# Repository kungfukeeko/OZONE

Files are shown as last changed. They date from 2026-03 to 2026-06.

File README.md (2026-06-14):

------  MJERENJE STUPCA OZONA  ------

Ovdje nam se nalaze svi bitni file-ovi za proizvesti i programirati instrument ☀️

Prioritet je:

1. Ugladiti i kalibrirati suncokret 🌻
2. Programirati ESP32 feature u ozone_v2.ino: izračun pozicije sunca -DONE-, slanje mjerenja preko weba -DONE- i prikaz na ekranu -DONE-, sleep-wakeup kontrola -TODO-💫💽💤
3. Spojiti sunflower.ino i ozone_v2.ino 👯
4. Dizajnirati poklopac za platformu ⛺
5. Redizajnirati platformu za metalni servo na vertikalnoj osi 🔭

Kako bi primili podatke preko WiFi-a na kraju mjerenja
- Create secrets.h , copy secrets.example.h and add your SECRET_WIFI_SSID, SECRET_WIFI_PASS, SECRET_PC_HOST
- Windows: install nmap and run command before measurement end: ncat -l 5000 > data.csv
- macOS : no need to install nmap, just run: nc -l 5000 > data.csv

File će biti spremljen pod data.csv, preimenuj ga prije idućeg mjerenja.
Ovo ću update-at po potrebi.

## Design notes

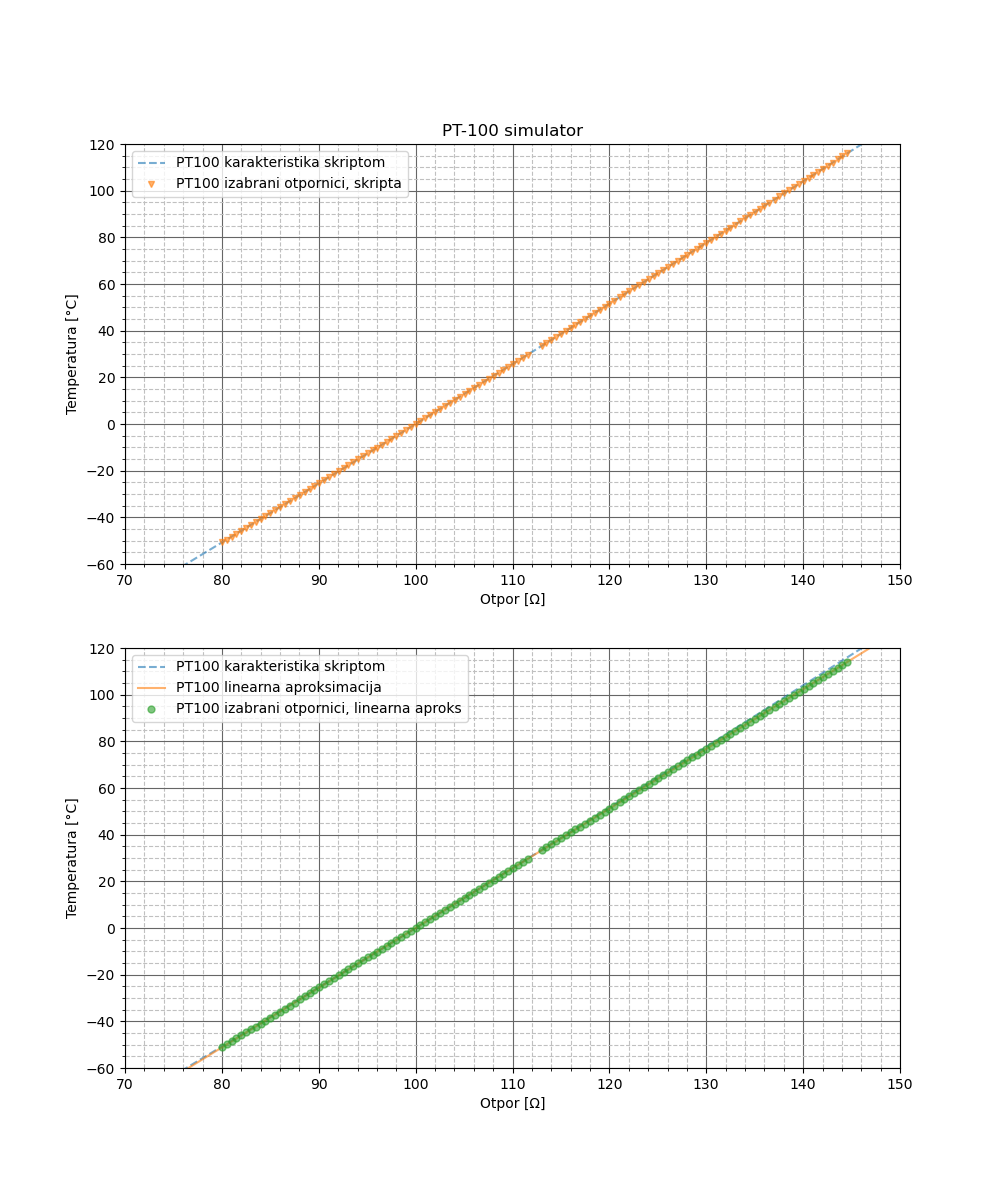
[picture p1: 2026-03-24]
Python - modeliranje i mjerenja/pt-100.png

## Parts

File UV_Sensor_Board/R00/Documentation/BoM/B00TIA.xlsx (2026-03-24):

Quantity | Designator | Manufacturer_Part_Number | JLC_Part_Number | Manufacturer_Name | Description | Footprint | MountingType | POPISČINA
1 | A1 | LP5907MFX-3.3/NOPB |  | Texas Instruments | LDO Voltage Regulators 250mA Ultra-Lo Noise LDO Reg | SOT-23-5 | SMD | Mouser
5 | C1, C12:1, C12:2, C14:1, C14:2 | C0805H103K5GACTU | CL21B103KBANNNC | Kemet | Multilayer Ceramic Capacitors MLCC - SMD/SMT 50V 0.01uF C0G 0805 10% | 0805 | SMD | Borealis
8 | C2, C3, C7, C8, C16:1, C16:2, C18:1, C18:2 | C0805C105K5RACTU | CL21B105KAFNFNE |  | Multilayer Ceramic Capacitors MLCC - SMD/SMT 50V 1uF X7R 0805 10% | 0805 | SMD | G4-4
1 | C4 | T495D106M035ATE250 | 293D106X9050E2TE3 | Kemet | Capacitor, Tantalum, 10uF, 35V, 20%, Low ESR, 250mΩ, Kemet | 2917 | SMD | G5-4 ili Borealis
9 | C5, C6, C10, C13:1, C13:2, C15:1, C15:2, C17:1, C17:2 | C0805C104K5RACTU | CL21B104KBCNNNC | Kemet | Multilayer Ceramic Capacitors MLCC - SMD/SMT 50V 0.1uF X7R 0805 10% | 0805 | SMD | G3-2 i G3-3
1 | C9 | C0603X224J5RACTU | 0603B224K250NT | Kemet | Multilayer Ceramic Capacitors MLCC - SMD/SMT 50V 0.22uF X7R 125C 0603 | 0603 | SMD | G3-6
2 | C11:1, C11:2 | C0805C101J5GAC3123 | CL21C101JBANNNC | Kemet | Multilayer Ceramic Capacitors MLCC - SMD/SMT 50V 100pF C0G 0805 5% | 0805 | SMD | G1-5
2 | D1:1, D1:2 | SG01S-18 |  | Sglux | SG01 series photodiode, TO18 housing | TO18 | THT
1 | FL1 | BLM21SP601BH1D | BLM21PG300SN1D | Murata Electronics | Ferrite Beads 600 OHM 2.3A FERRITE-BEAD | 0805 | SMD | H1-6 ali je 0603
1 | IC1 | ADS131M03IPWR |  | Texas Instruments | Analog to Digital Converters - ADC Three-channel 24-bi t 64-kSPS | TSSOP-20 | SMD | J-5-6
2 | IC2:1, IC2:2 | OPA387DBVT |  | Texas Instruments | Precision Amplifiers Ultra-high precision (2 uV) zero-drift | SOT-23-5 | SMD | Mouser
2 | IC3:1, IC3:2 | LMP7721MA |  | Texas Instruments | Precision Amplifiers 3 FEMTOAMPERE INPUT BIAS CURR PREC AMP | SOIC-8 | SMD | Mouser
1 | J1 | 61301611121 | / | Wurth Elektronik | Headers & Wire Housings WR-PHD 2.54mm Hdr 16 P Single Str Gold |  | THT
1 | J2 | 61301211121 | / | Wurth Elektronik | Headers & Wire Housings WR-PHD 2.54mm Hdr 12 P Single Str Gold |  | THT
7 | J3, J4, J5, J6, J7, J8, J9 | 61300211121 | / | Wurth Elektronik | Headers & Wire Housings WR-PHD 2.54mm 2Pin T HT Header |  | THT
7 | R1, R8:1, R8:2, R9:1, R9:2, R10:1, R10:2 | CRCW08051K00JNEC | 0805W8F1001T5E | Vishay | Thick Film Resistors D12/CRCW0805 200 1K0 5% ET6 e3 | 0805 | SMD | E4-6
3 | R3, R4, R5 | CRCW080510K0FKEA | 0805W8F1002T5E | Vishay | Thick Film Resistors 1/8watt 10Kohms 1% 100ppm | 0805 | SMD | F1-2
2 | R6:1, R6:2 | CRHV1206AF20M0FKFT | 1206W4F2005T5E | Vishay | Thick Film Resistors 20Mohms 1% 100ppm 0.3watt 3-side term | 1206 | SMD | Mouser
2 | R7:1, R7:2 | CRCW08054K70FKEA | 0805W8F4701T5E | Vishay | Resistor, Thick Film, 4K7, 1%, 0.125W, TK100, Vishay | 0805 | SMD | E5-6
2 | R11:1, R11:2 |  | 0805W8F0000T5E | Vishay | 0R | 0805 | SMD | E1-1
2 | X1:1, X1:2 | 73251-3140 | / | Molex | Connector, Receptacle, SMA, RF, 50Ohm, Molex |  | THT
1 | Y1 | ECS-2520MVLC-080-BN-TR | OT25208MJBA4SL | ECS | Standard Clock Oscillators MultiVolt ECS-2520MVLC,Active,XO (Standard),8MHz,Enable/Disable,CMOS,1.8V, 2.5V, 3.3V,+/-50ppm,-40C - 85C,Surface Mount,4-SMD, No Lead,0.098" L x 0.079" W (2.50mm x 2.00mm),0.035" (0.90mm) | SMD2520-4P | SMD | Mouser

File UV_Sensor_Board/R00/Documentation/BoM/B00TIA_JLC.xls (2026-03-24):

Comment | Designator | Footprint | JLCPCB Part #
ECS | Y1 | SMD2520-4P | C717682
Vishay | R6:1,R6:2 | 1206 | C71198
TexasInstruments | IC3:1,IC3:2 | SOIC-8 | C124427
Vishay | R7:1,R7:2 | 0805 | C17673
MultilayerCeramicCapacitorsMLCC-SMD/SMT50V0.22uFX7R125C0603 | C9 | C0603X224J5RACTU | C1606
Kemet | C1,C12:1,C12:2,C14:1,C14:2 | 0805 | C1710
Kemet | C11:1,C11:2 | 0805 | C1790
MurataElectronics | FL1 | 805 | C16903
 | C2,C3,C7,C8,C16:1,C16:2,C18:1,C18:2 | 0805 | C1712
TexasInstruments | IC1 | TSSOP-20 | C5215163
TexasInstruments | IC2:1,IC2:2 | SOT-23-5 | C4370041
ThickFilmResistorsD12/CRCW08052001K05%ET6e3 | R1,R8:1,R8:2,R9:1,R9:2,R10:1,R10:2 | 0805W8F1001T5E | C17513
Kemet | C5,C6,C10,C13:1,C13:2,C15:1,C15:2,C17:1,C17:2 | 0805 | C1711
Vishay | R3,R4,R5 | 0805 | C17414
0R | R11:1,R11:2 | 0805W8F0000T5E | C17477
TexasInstruments | A1 | SOT-23-5 | C80670
Kemet | C4 | 2917 | C1952737

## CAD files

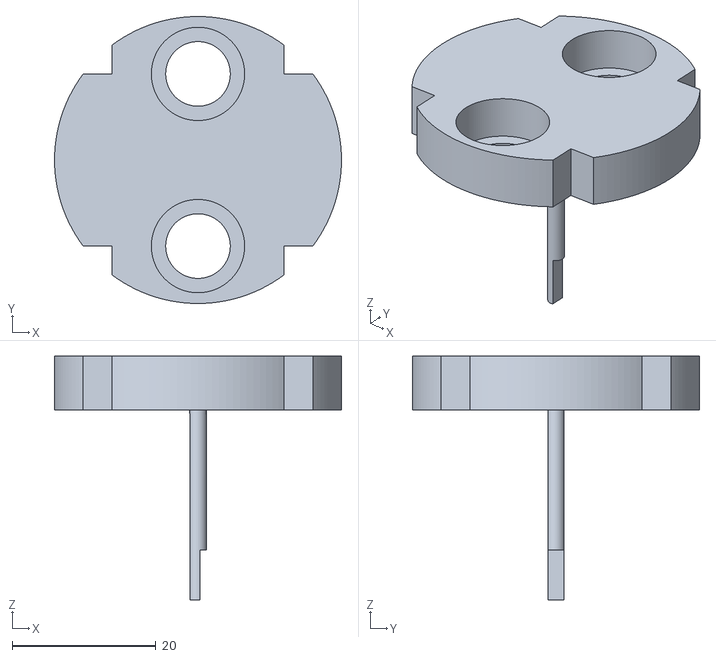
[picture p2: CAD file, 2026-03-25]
Filter_Holder/casev3-FILTER2.stl
40.0 x 40.0 x 34.0

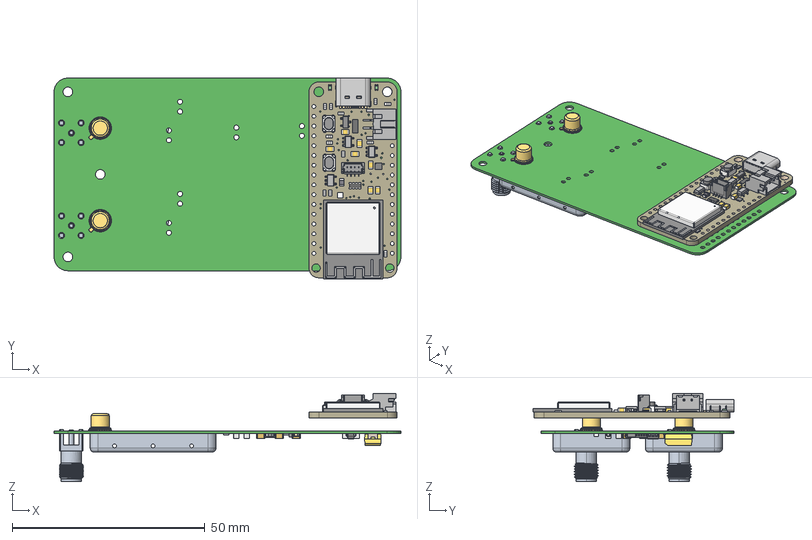
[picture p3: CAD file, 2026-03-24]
UV_Sensor_Board/R00/Documentation/STEP_model/PB00TIA.step
90.0 x 52.2 x 22.9 mm
Leader x 5
Mid_Body x 14
Mark x 14
Case_Bottom_Tant3
Case_Top_Tant3
Case_Cathode_Tant3
Case_Anode_Tant3
term1 x 2
term2 x 2
BODY-SOT x 2
LEAD-SOT x 10
LEAD-DUMMY x 2
C0603
Pins
BODY-SO x 2
LEAD-D0008A x 16
BODY-TSSOP
LEAD-TSSOP x 20
PIN1
MS326-10F x 2
Board
0805-NO x 7
SOT23-5 x 3
SOD-123
JSTPH2_BATT
CHIPLED_0603_NOOUTLINE x 2
0603-NO x 12
BTN_KMR2_4.6X2.8 x 2
SOT23-R
USB_C_CUSB31-CFM2AX-01-X
QFN60_ESP32-S2-MINI-1_EXP
WLCSP9
JST_SH4_RA
SK6805_1515
_0805MP
RESPACK_4X0603

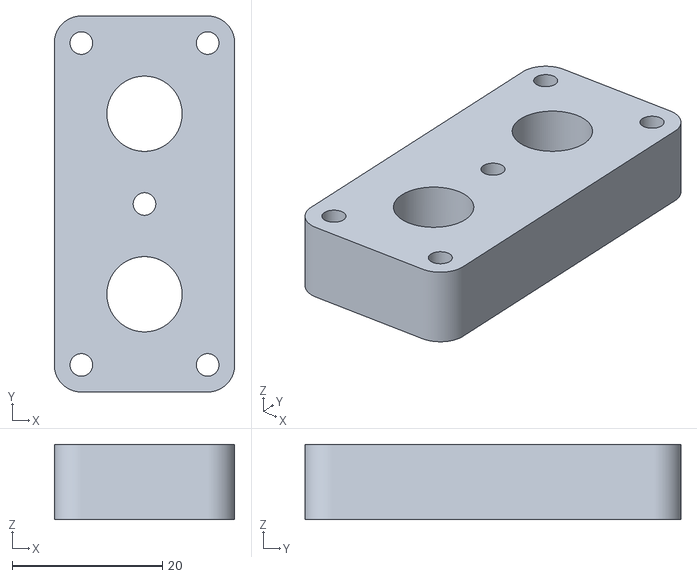
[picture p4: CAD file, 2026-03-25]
Filter_Holder/casev3-BASE.stl
24.0 x 50.0 x 10.0

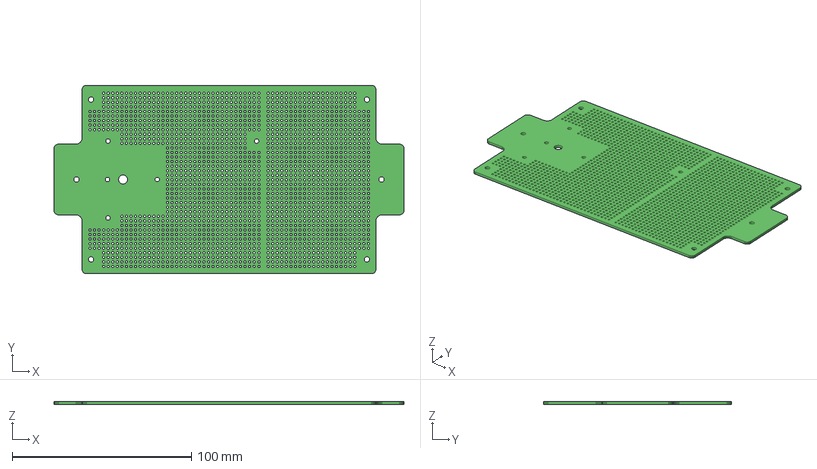
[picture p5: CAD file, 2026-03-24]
UV_Sensor_Board/R00/Documentation/STEP_model/protorupe.step
195.0 x 105.0 x 1.59 mm

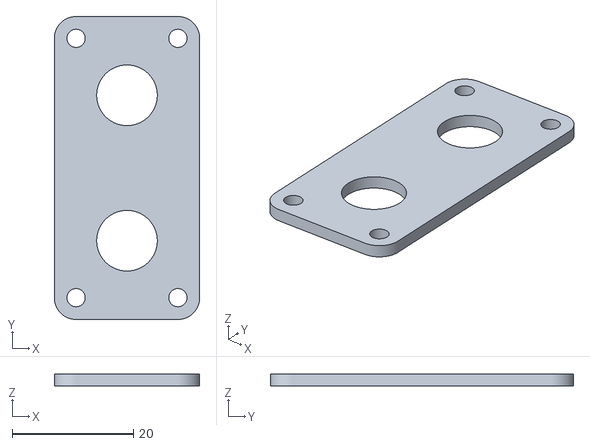
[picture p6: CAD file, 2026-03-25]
Filter_Holder/casev3-COVER.stl
24.0 x 50.0 x 2.00

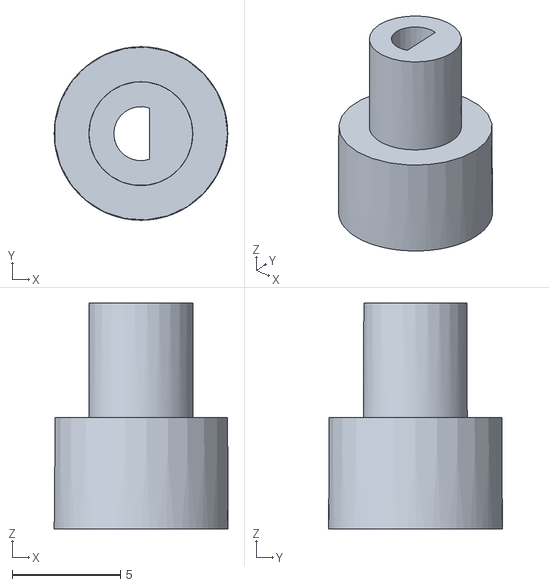
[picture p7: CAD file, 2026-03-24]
Filter_Holder/casev3-COUPLER_SCALED.stl
8.03 x 8.03 x 10.4

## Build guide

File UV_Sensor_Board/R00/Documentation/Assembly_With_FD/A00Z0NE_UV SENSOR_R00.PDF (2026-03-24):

A

B

C

D

E

1 | 1
2 | 2
3 | 3
4 | 4

# Assembly Instructions

- All used additional materials and procedures in the process must comply with REACH and RoHS EU directives.
- All processes must be carried out in accordance with J-STD-001 and IPC-7711/IPC-7721 Class 2, IEC 61340-5.
- The final result of all processes must meet IPC-A-610 Class 2.
- The standards, norms, directives, procedures that are mentioned must be used in the latest valid edition.

General instructions for applying additional surface protection - a layer of coating, valid for both sides of the PCB:

# Surface protection:

- Sheets 3 and 4 show the assembly of components.
- Sheets 5 and 6 show the surface protection.

# Remark:

Sheet: | Sheets:
4 | 4 | PromjeneAss | 4 | Ovaj dokument ostaje u isključivom vlasništvu KONČAR - INSTITUT ZA ELEKTROTEHNIKU. Pretisak i upotreba izvan namjene nisu dozvoljeni. | | Date: 29.5.2025. | Title: UV SENSOR | Number: A00Z0NE
| | | | | | Author: K.Stepančić
| | | | | | Checked By: M.Babić
| | PromjeneAss | | | | Approved By: D.Babić
Ed. | Version | Date | Name | | fiet 40422a/2

## File: A00Z0NE_UV SENSOR_R00.Pdf

This document remains the exclusive property of the KONČAR - ELECTRICAL ENGINEERING INSTITUTE. Reproduction or any use not in conformity with
the intended application is not permissible.

Revision:

Instructions for carrying out the process of assembly, testing, finishing, repair and final control:

- The module must necessarily undergo a washing process, i.e. removal of flux residues, grease, etc. before coating.
- The module must necessarily undergo a drying process before coating, at approximately the following temperature/duration: 60°C/6h or 40°C/12h.
- It is necessary to coat masked and unmasked traces, exposed parts of the PCB, component solder joints or exposed contacts.
- If the component is not mounted, it is necessary to coat the empty solder joints of the component.
- Coating of the module is possible manually and mechanically.
- The final result must meet IPC-A-610 Class 2, the thickness of the coating must be within the limits of 0.03-0.13mm.

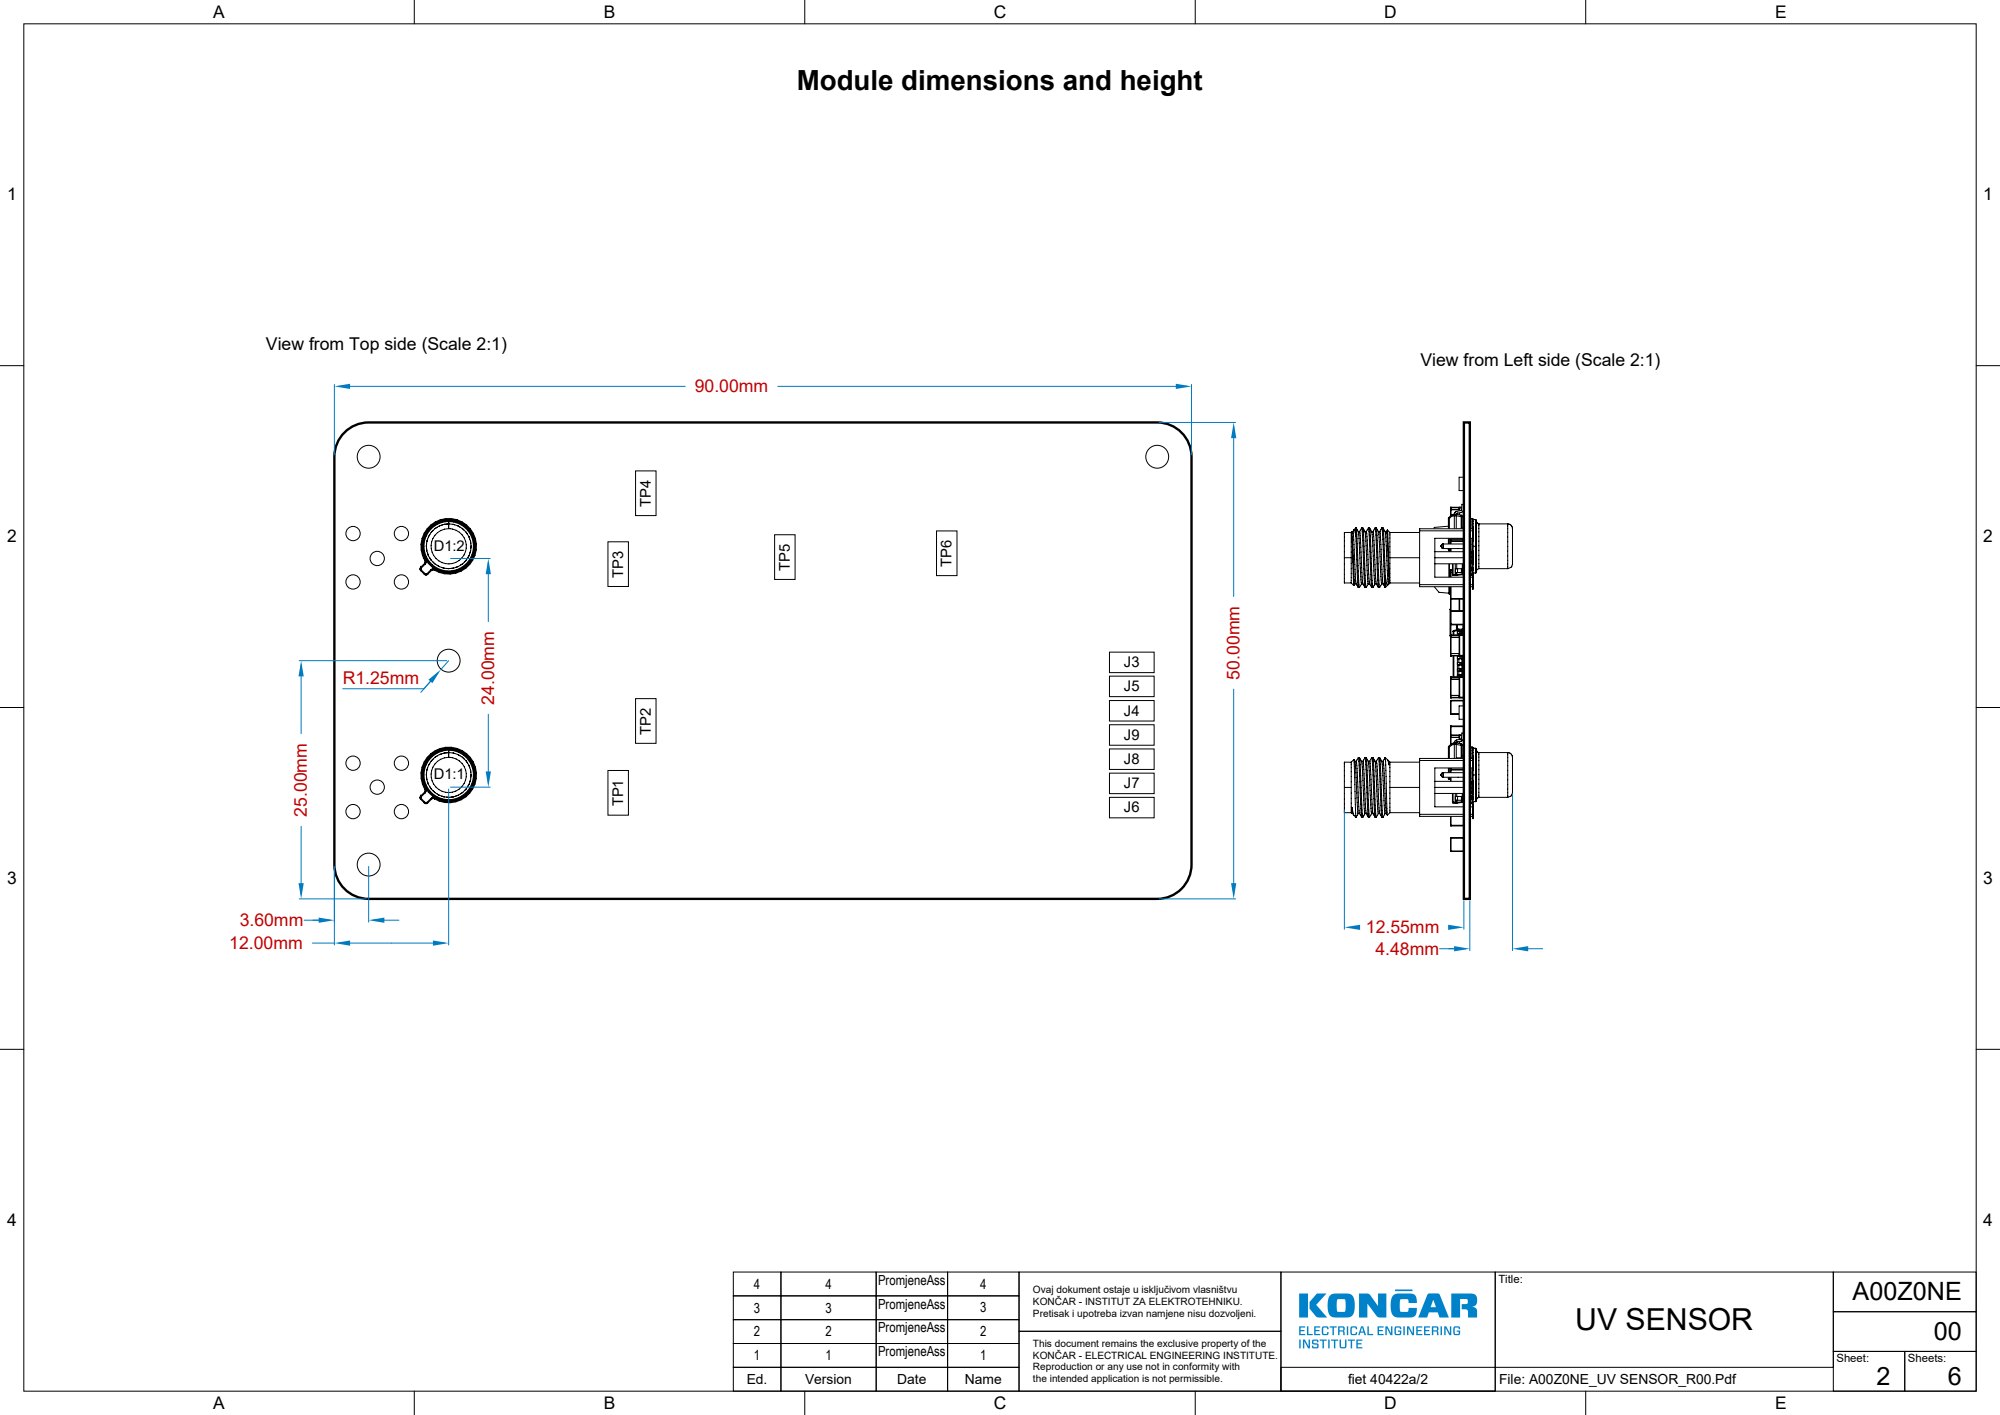
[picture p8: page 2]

Module dimensions and height

View from Top side (Scale 2:1)

View from Left side (Scale 2:1)

Ovaj dokument ostaje u isključivom vlasništvu

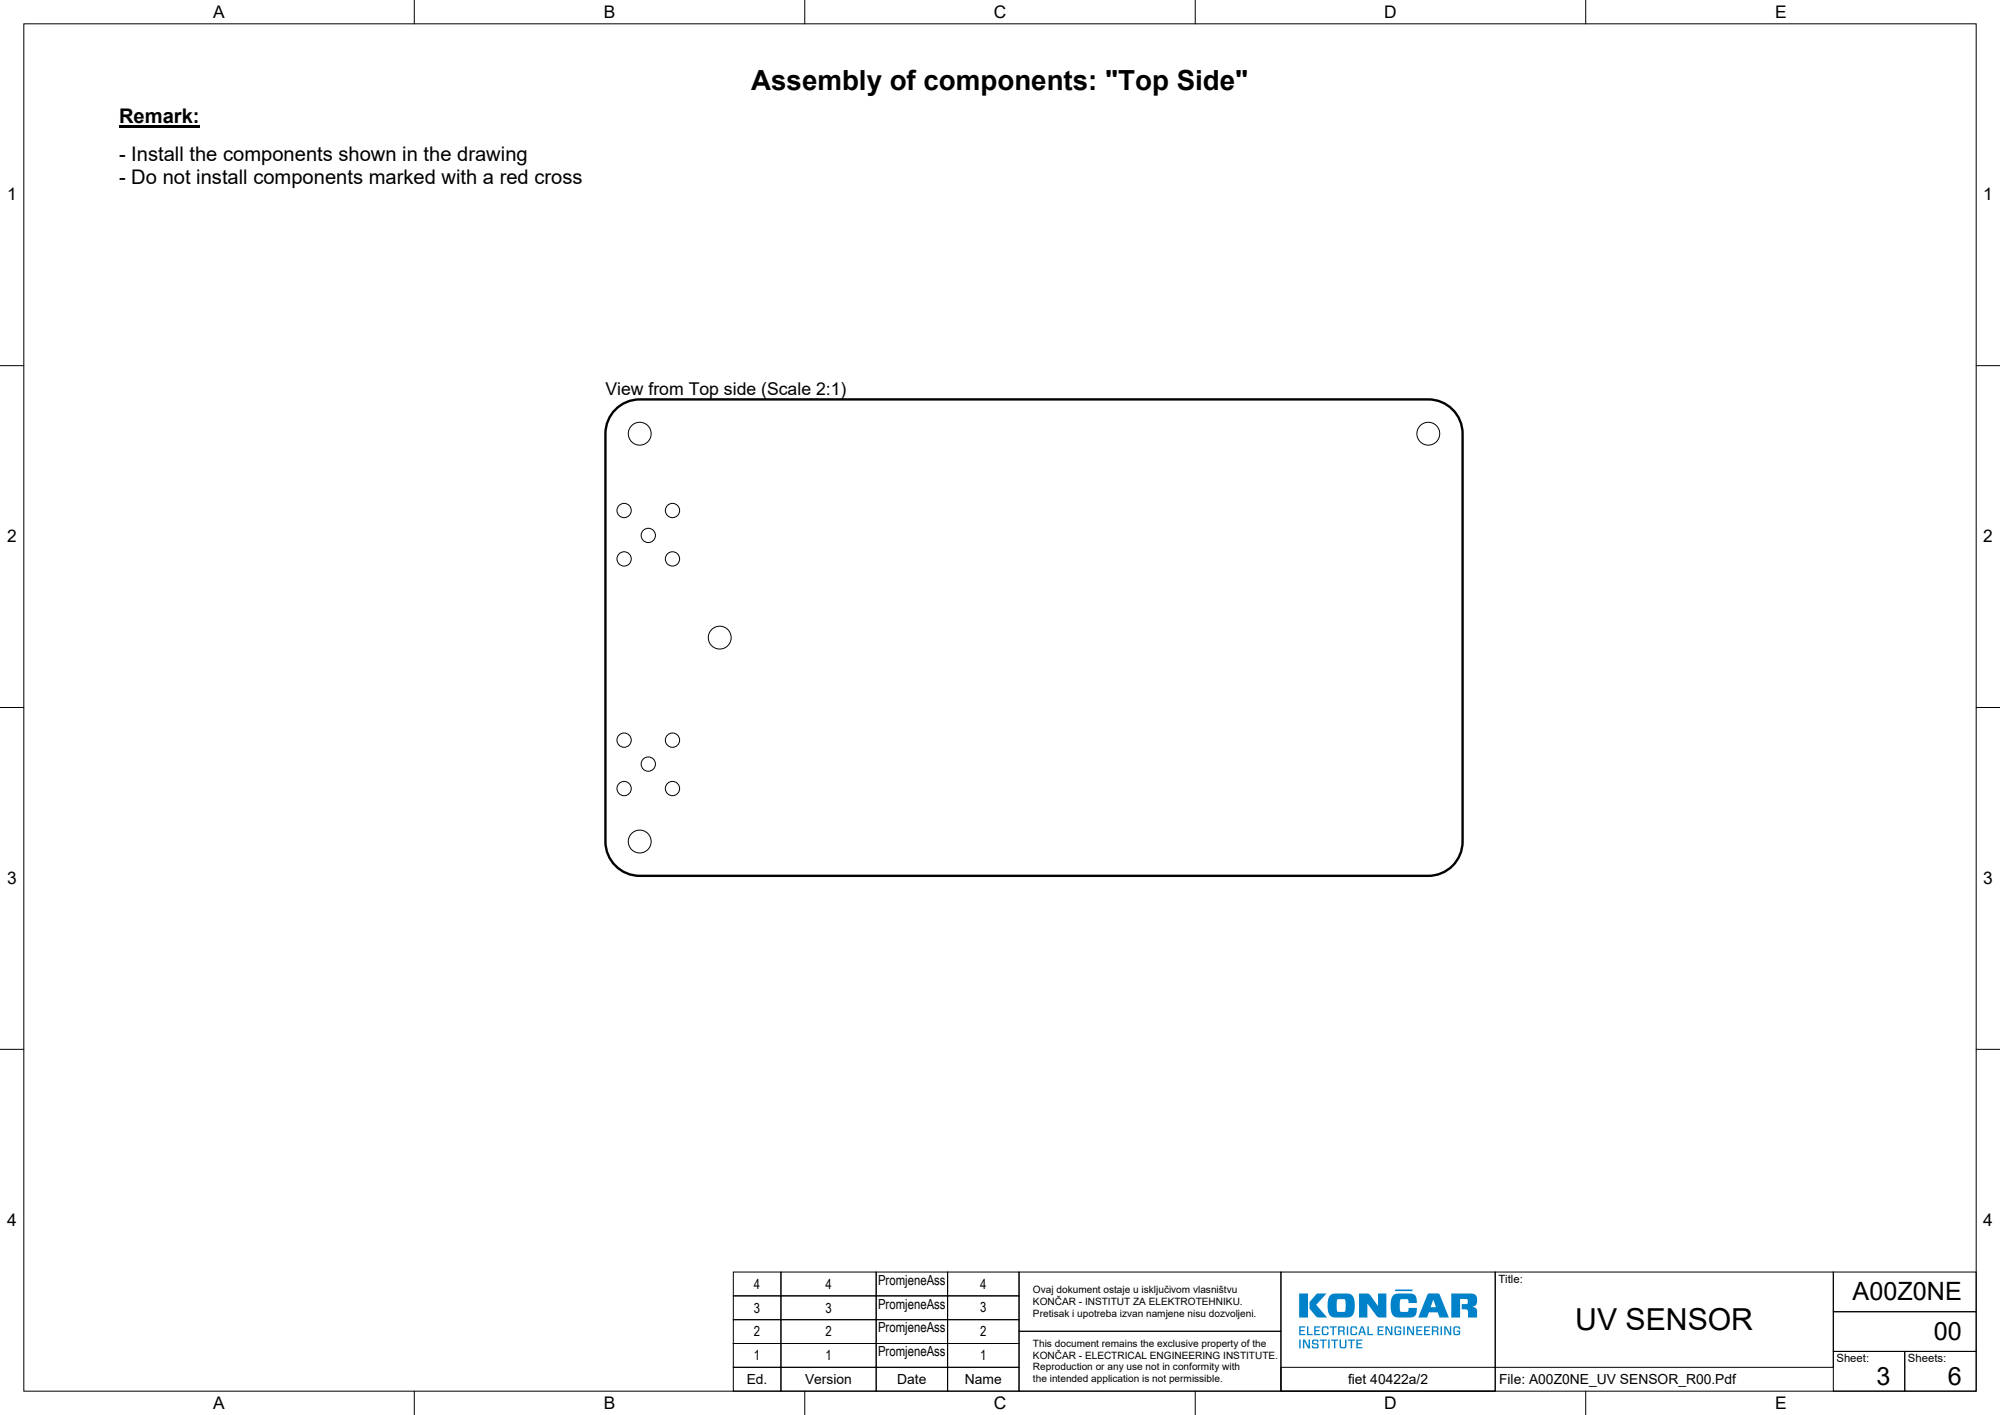
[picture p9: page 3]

Assembly of components: "Top Side"

Remark:
- Install the components shown in the drawing
- Do not install components marked with a red cross

View from Top side (Scale 2:1)

Ovaj dokument ostaje u isključivom vlasništvu

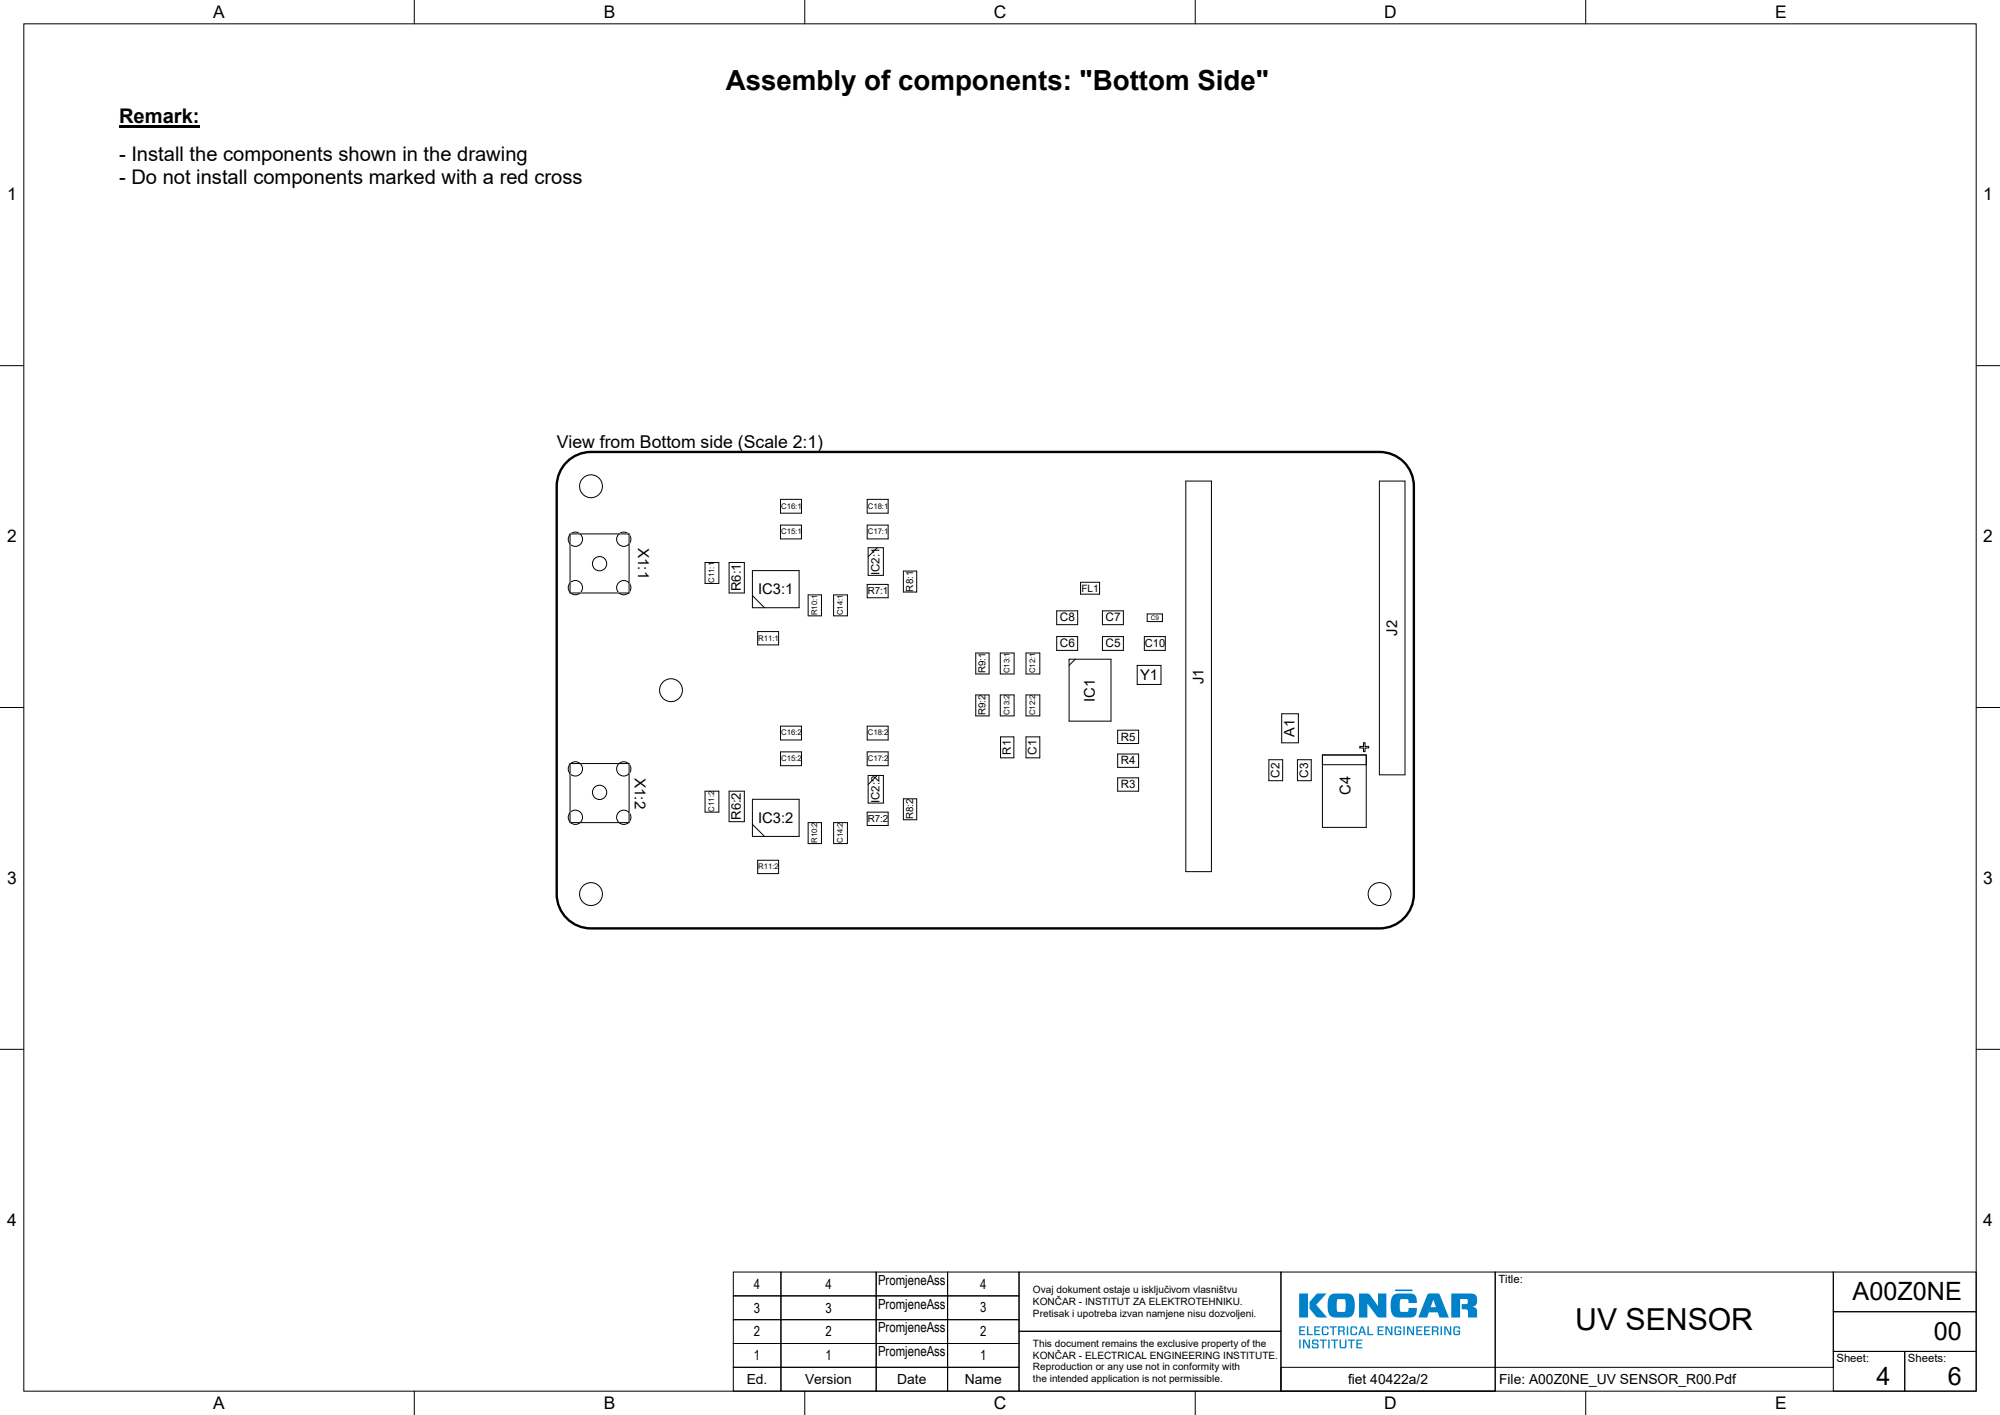
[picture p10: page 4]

Assembly of components: "Bottom Side"

- Install the components shown in the drawing
- Do not install components marked with a red cross

View from Bottom side (Scale 2:1)

Ovaj dokument ostaje u isključivom vlasništvu

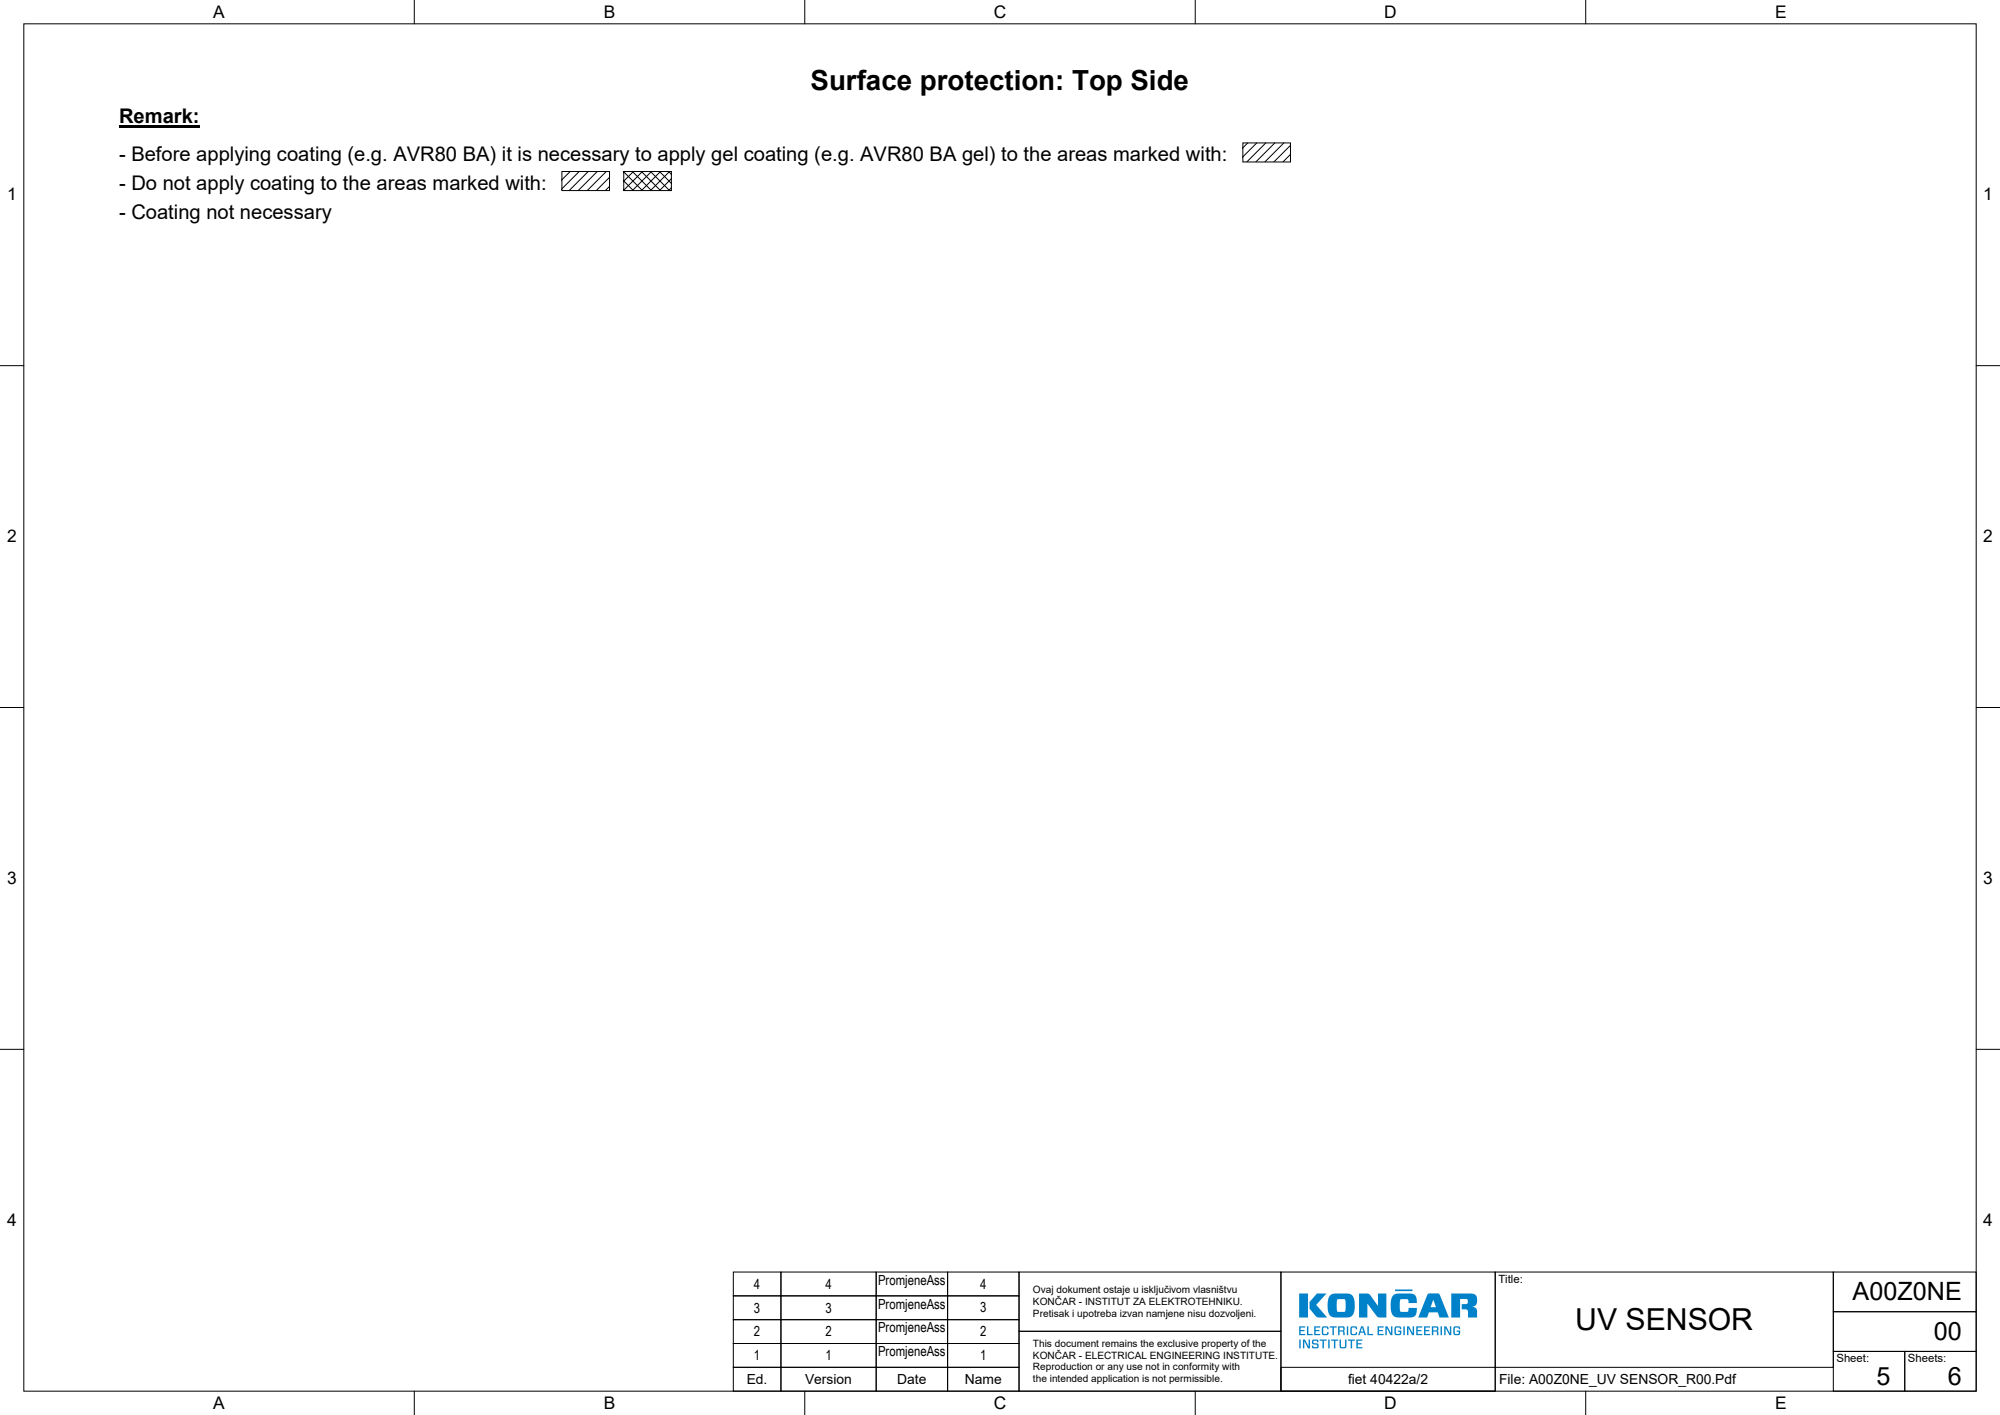
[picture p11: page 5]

Surface protection: Top Side

- Before applying coating (e.g. AVR80 BA) it is necessary to apply gel coating (e.g. AVR80 BA gel) to the areas marked with:
- Do not apply coating to the areas marked with:
- Coating not necessary

Ovaj dokument ostaje u isključivom vlasništvu

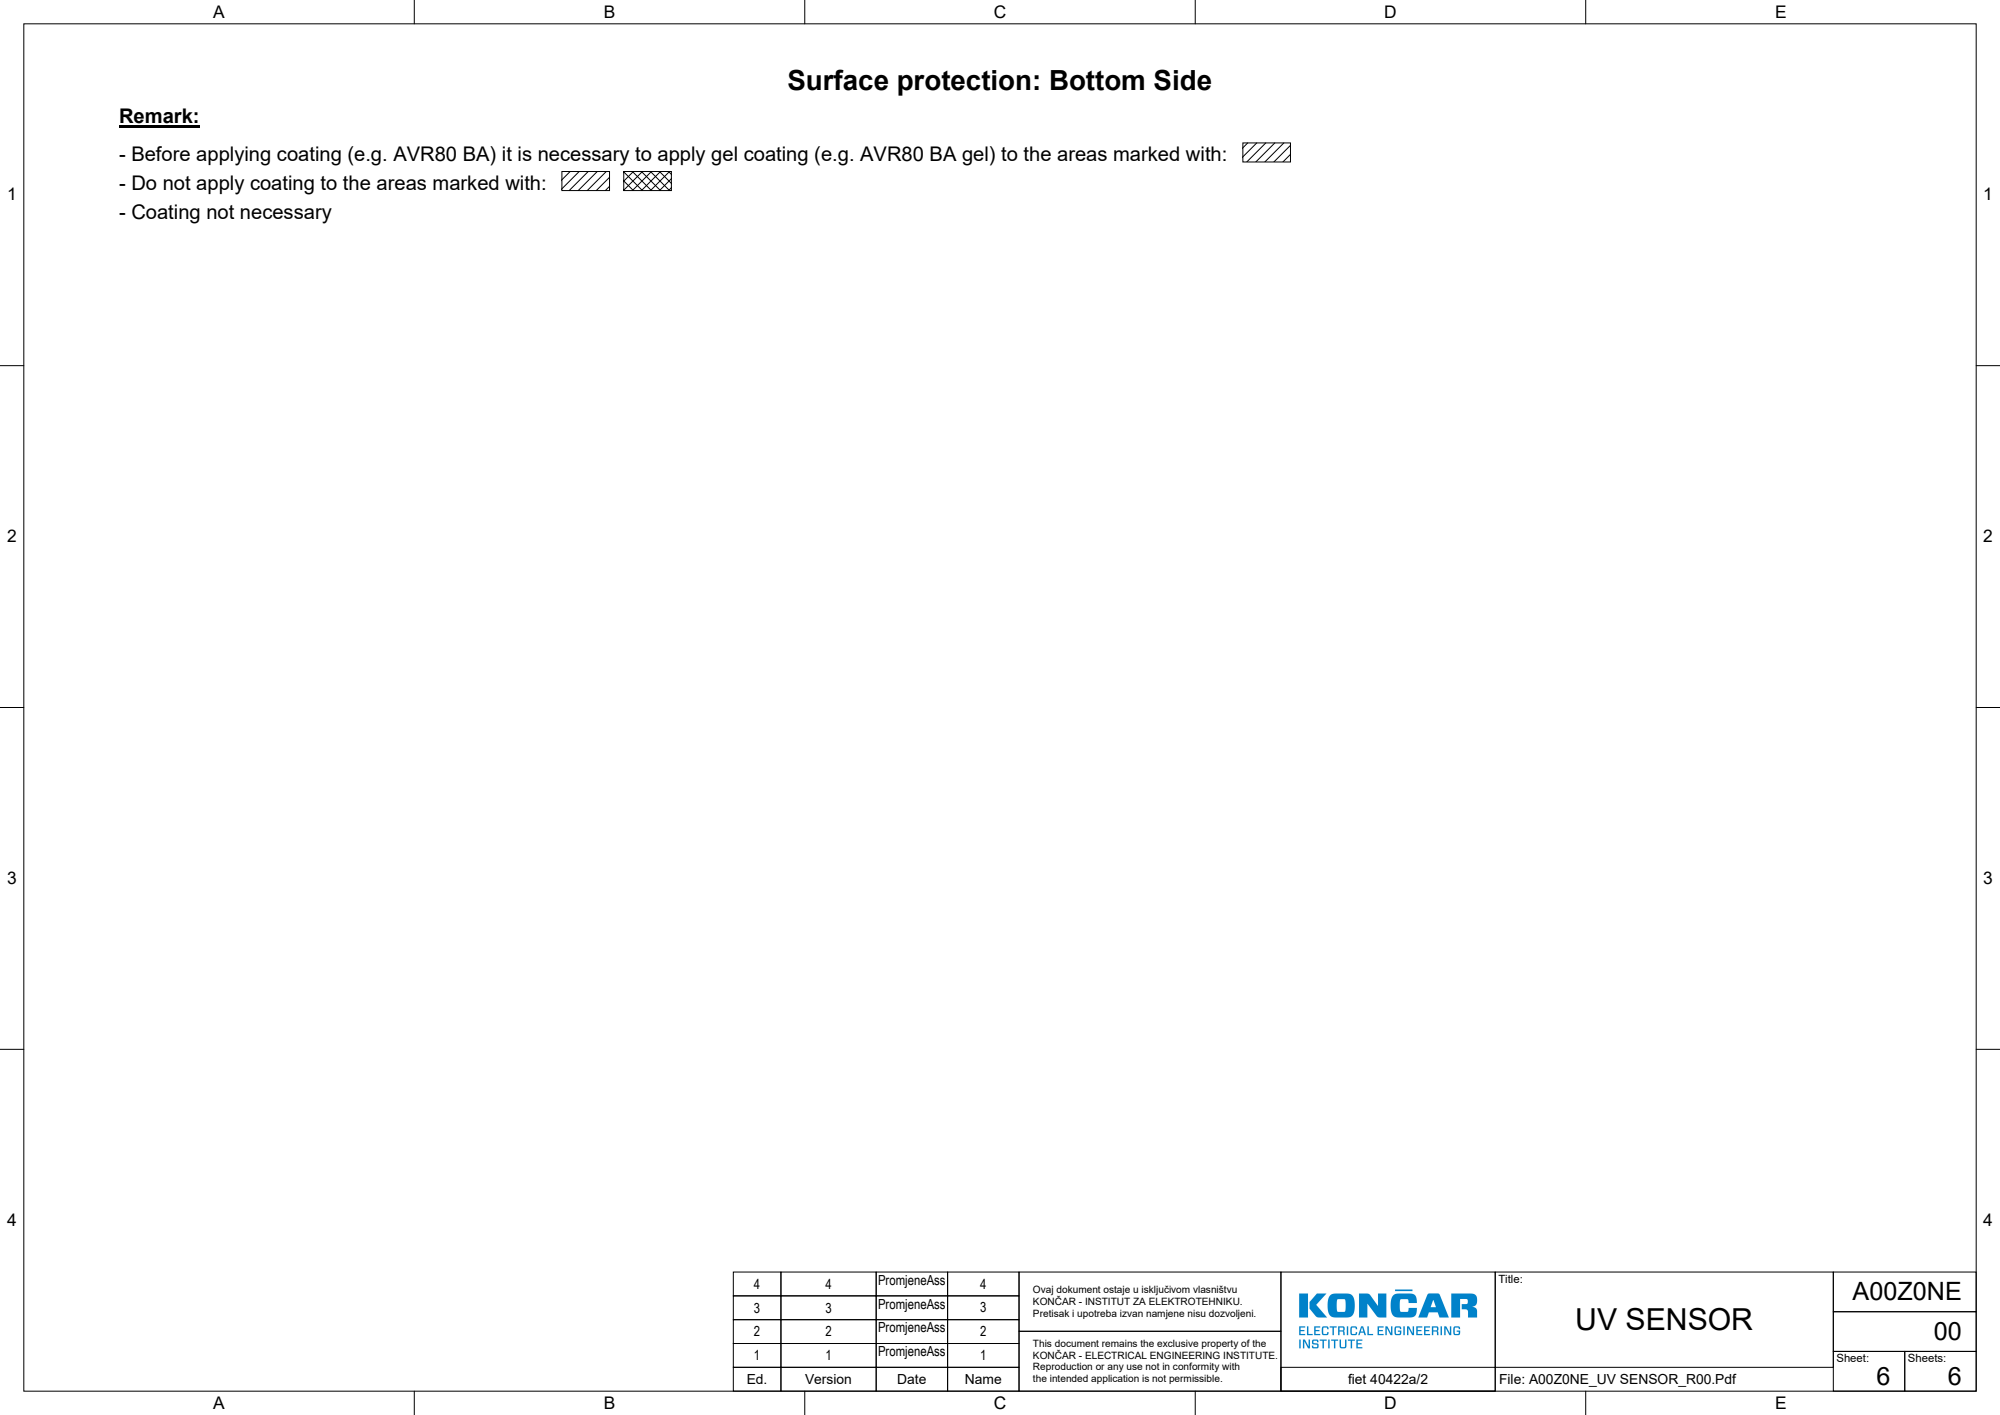
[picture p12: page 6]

Surface protection: Bottom Side

- Before applying coating (e.g. AVR80 BA) it is necessary to apply gel coating (e.g. AVR80 BA gel) to the areas marked with:
- Do not apply coating to the areas marked with:
- Coating not necessary

Ovaj dokument ostaje u isključivom vlasništvu

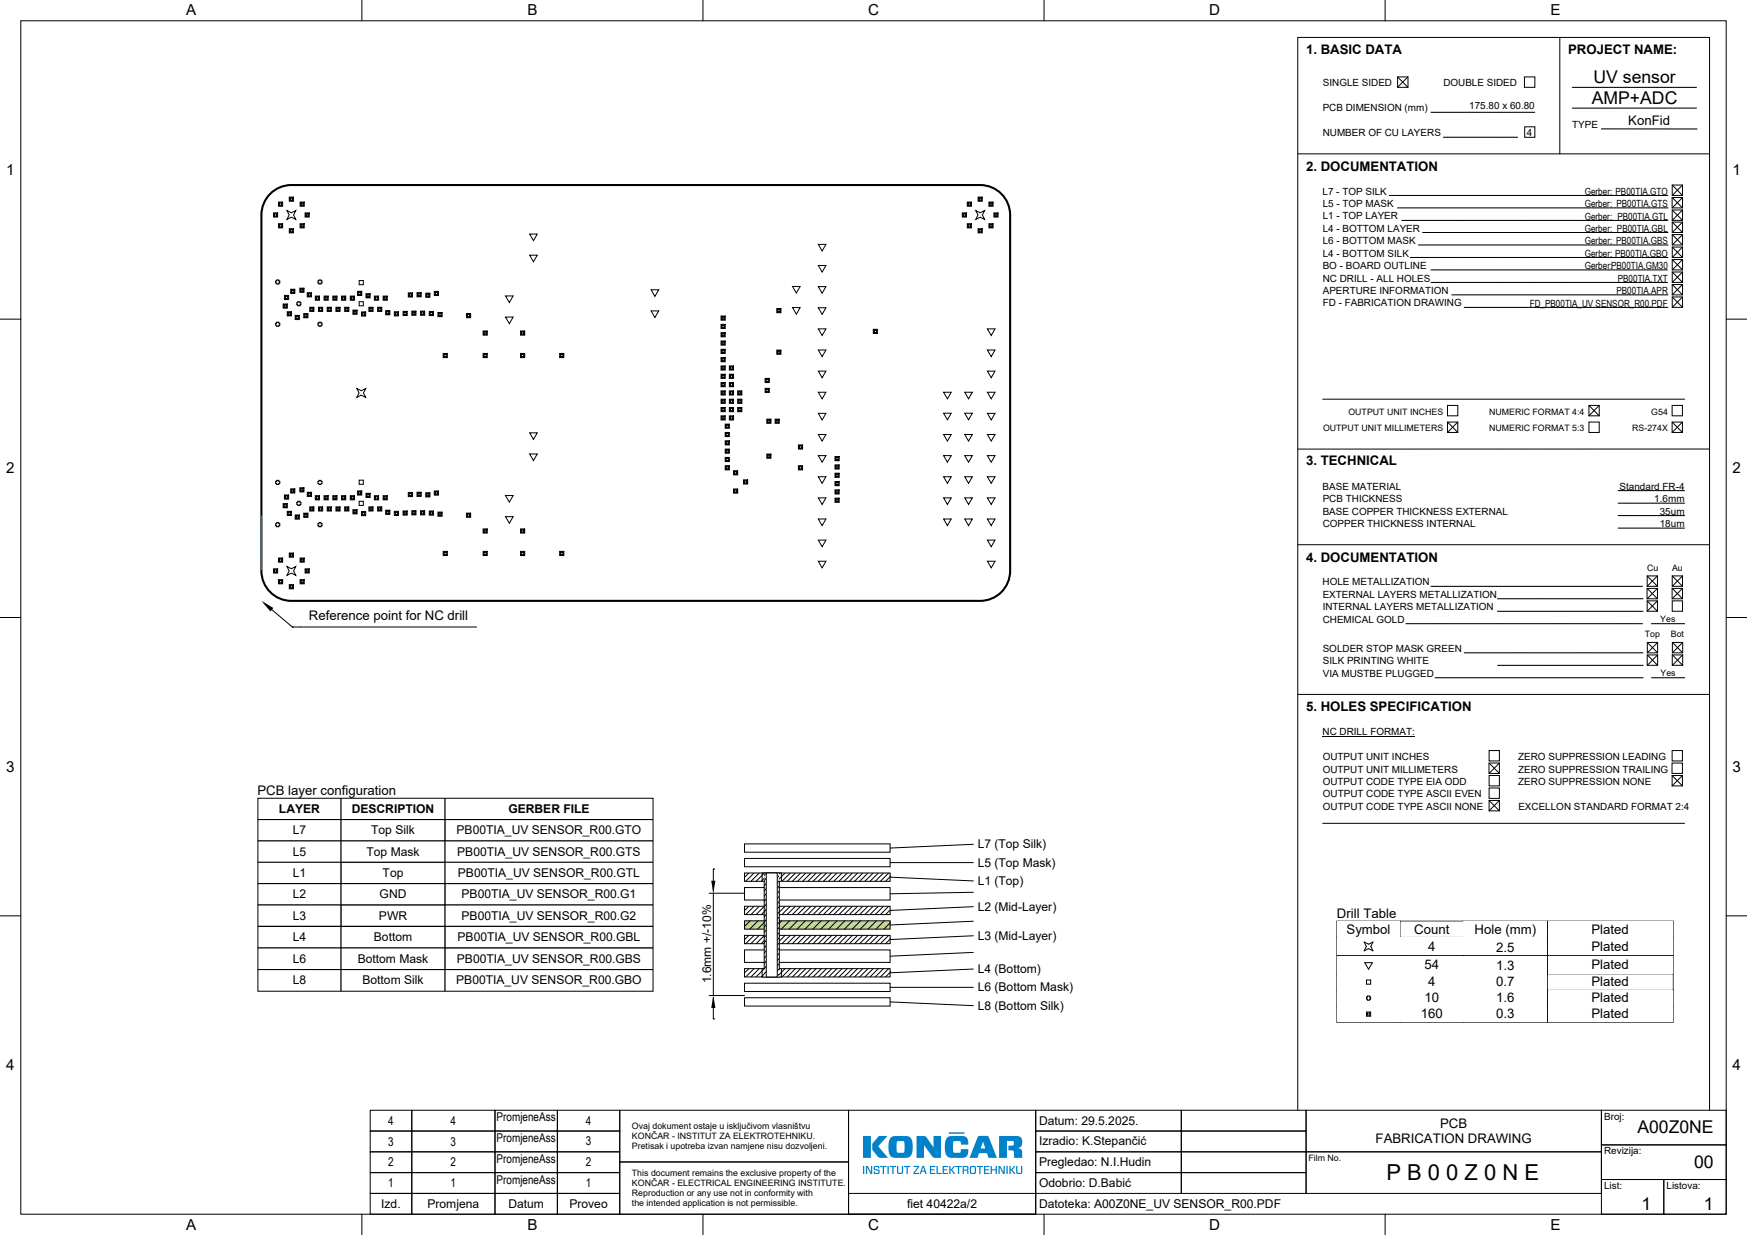
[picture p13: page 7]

1. BASIC DATA PCB DIMENSION (mm) 175.80 x 60.80 | PROJECT NAME: UV sensor AMP+ADC KonFid TYPE

NUMBER OF CU LAYERS

2. DOCUMENTATION

L7 - TOP SILK
L5 - TOP MASK
L1 - TOP LAYER
L4 - BOTTOM LAYER
BO - BOARD OUTLINE
NC DRILL - ALL HOLES
APERTURE INFORMATION
FD - FABRICATION DRAWING

BASE MATERIAL
PCB THICKNESS
BASE COPPER THICKNESS EXTERNAL
COPPER THICKNESS INTERNAL

Reference point for NC drill

SOLDER STOP MASK GREEN
SILK PRINTING WHITE

5. HOLES SPECIFICATION NC DRILL FORMAT: Drill Table

OUTPUT UNIT MILLIMETERS
OUTPUT CODE TYPE EIA ODD
OUTPUT CODE TYPE ASCII EVEN
OUTPUT CODE TYPE ASCII NONE

LAYER | DESCRIPTION | GERBER FILE
L7 | Top Silk | PB00TIA_UV SENSOR_R00.GTO
L5 | Top Mask | PB00TIA_UV SENSOR_R00.GTS
L1 | Top | PB00TIA_UV SENSOR_R00.GTL
L2 | GND | PB00TIA_UV SENSOR_R00.G1
L3 | PWR | PB00TIA_UV SENSOR_R00.G2
L4 | Bottom | PB00TIA_UV SENSOR_R00.GBL
L6 | Bottom Mask | PB00TIA_UV SENSOR_R00.GBS
L8 | Bottom Silk | PB00TIA_UV SENSOR_R00.GBO

Symbol | Count | Hole (mm) | Plated

4 | 2.5 | Plated
54 | 1.3 | Plated
4 | 0.7 | Plated
10 | 1.6 | Plated
160 | 0.3 | Plated

4 | 4 | PromjeneAss | 4 | Ovaj dokument ostaje u isključivom vlasništvu | | Datum: 29.5.2025. | PCB FABRICATION DRAWING | Broj: A00Z0NE

Izradio: K.Stepančić
Pregledao: N.I.Hudin | Film No. P B 0 0 Z 0 N E
Odobrio: D.Babić

List: | Listova:

Izd. | Promjena | Datum | Proveo | | fiet 40422a/2

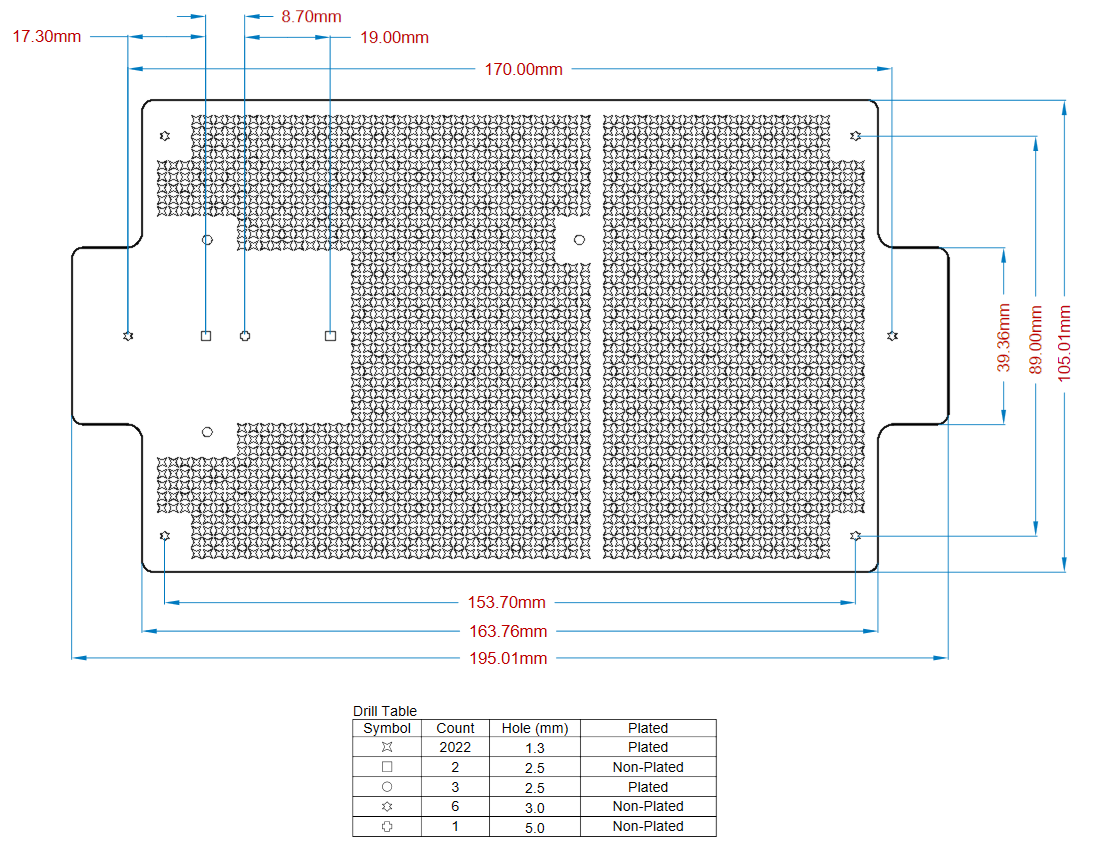
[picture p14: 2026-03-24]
UV_Sensor_Board/R00/Documentation/Assembly_With_FD/protorupe.png

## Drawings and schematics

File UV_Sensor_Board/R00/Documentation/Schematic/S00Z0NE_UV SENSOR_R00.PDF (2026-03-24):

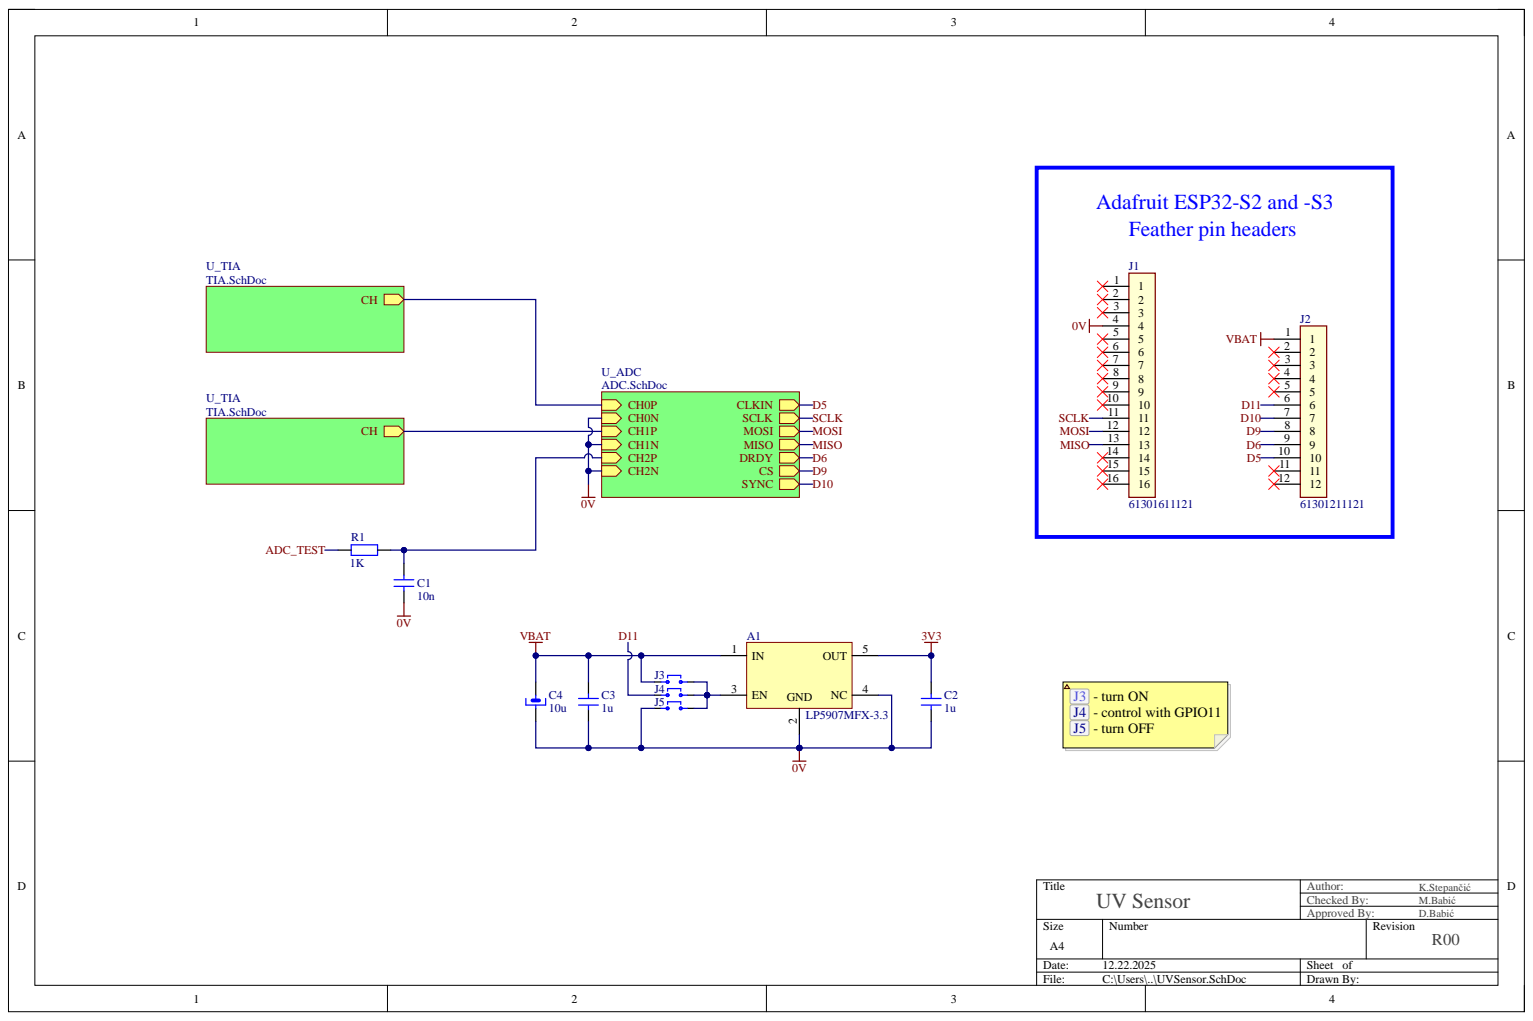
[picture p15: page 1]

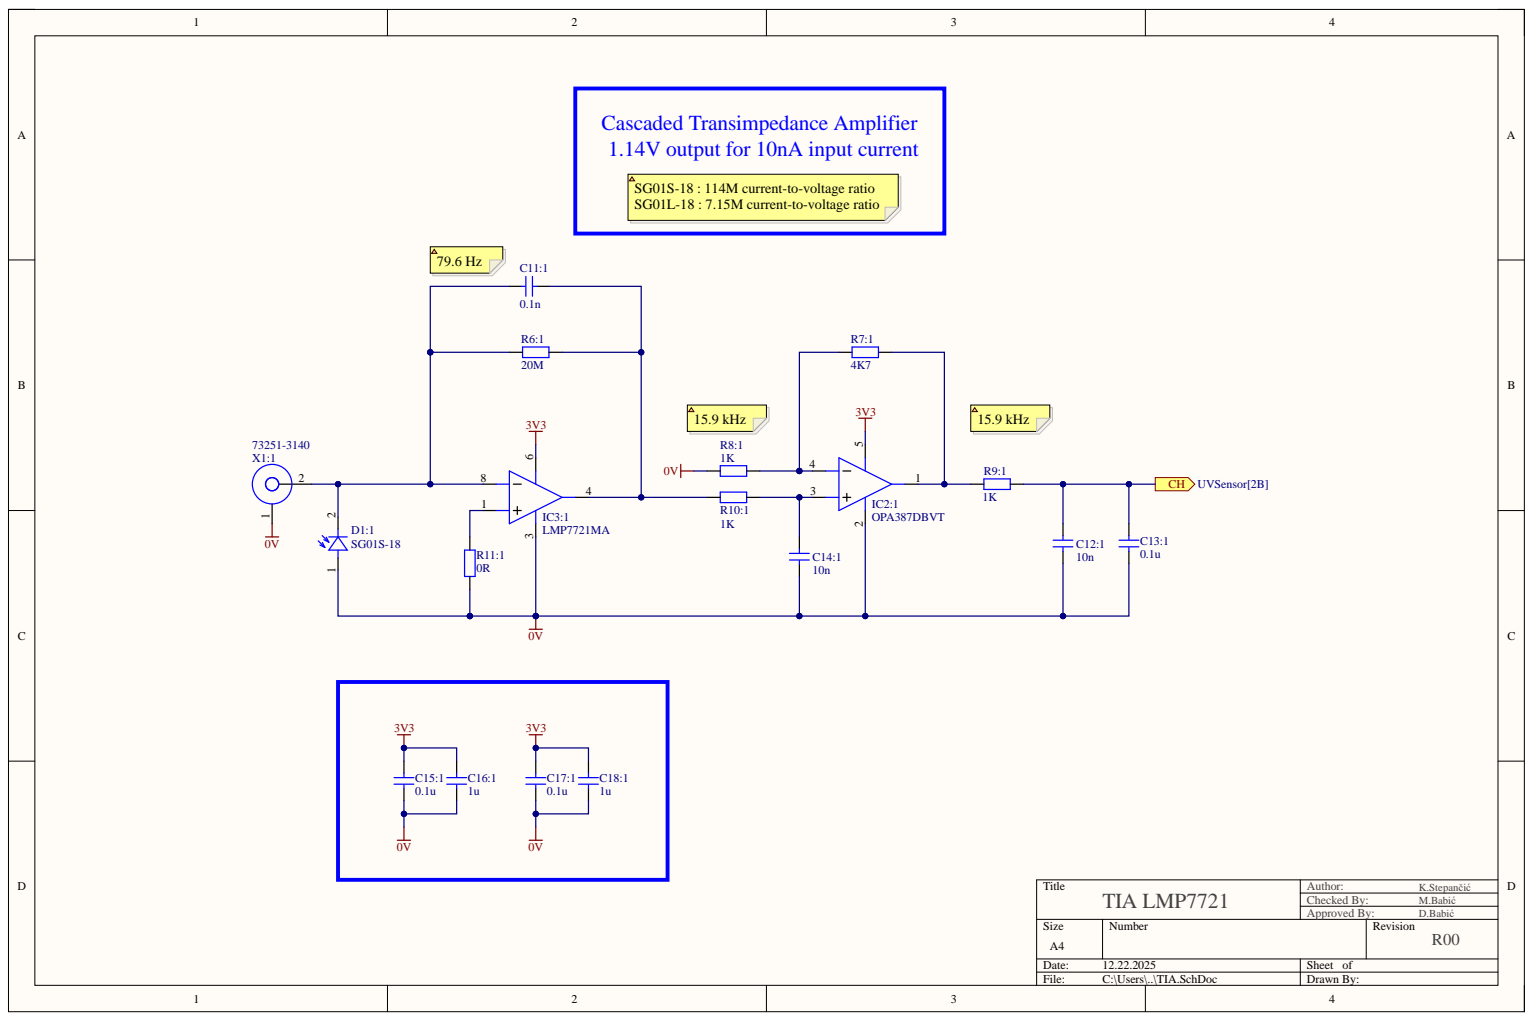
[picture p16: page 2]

Cascaded Transimpedance Amplifier
1.14V output for 10nA input current

SG01S-18 : 114M current-to-voltage ratio
SG01L-18 : 7.15M current-to-voltage ratio

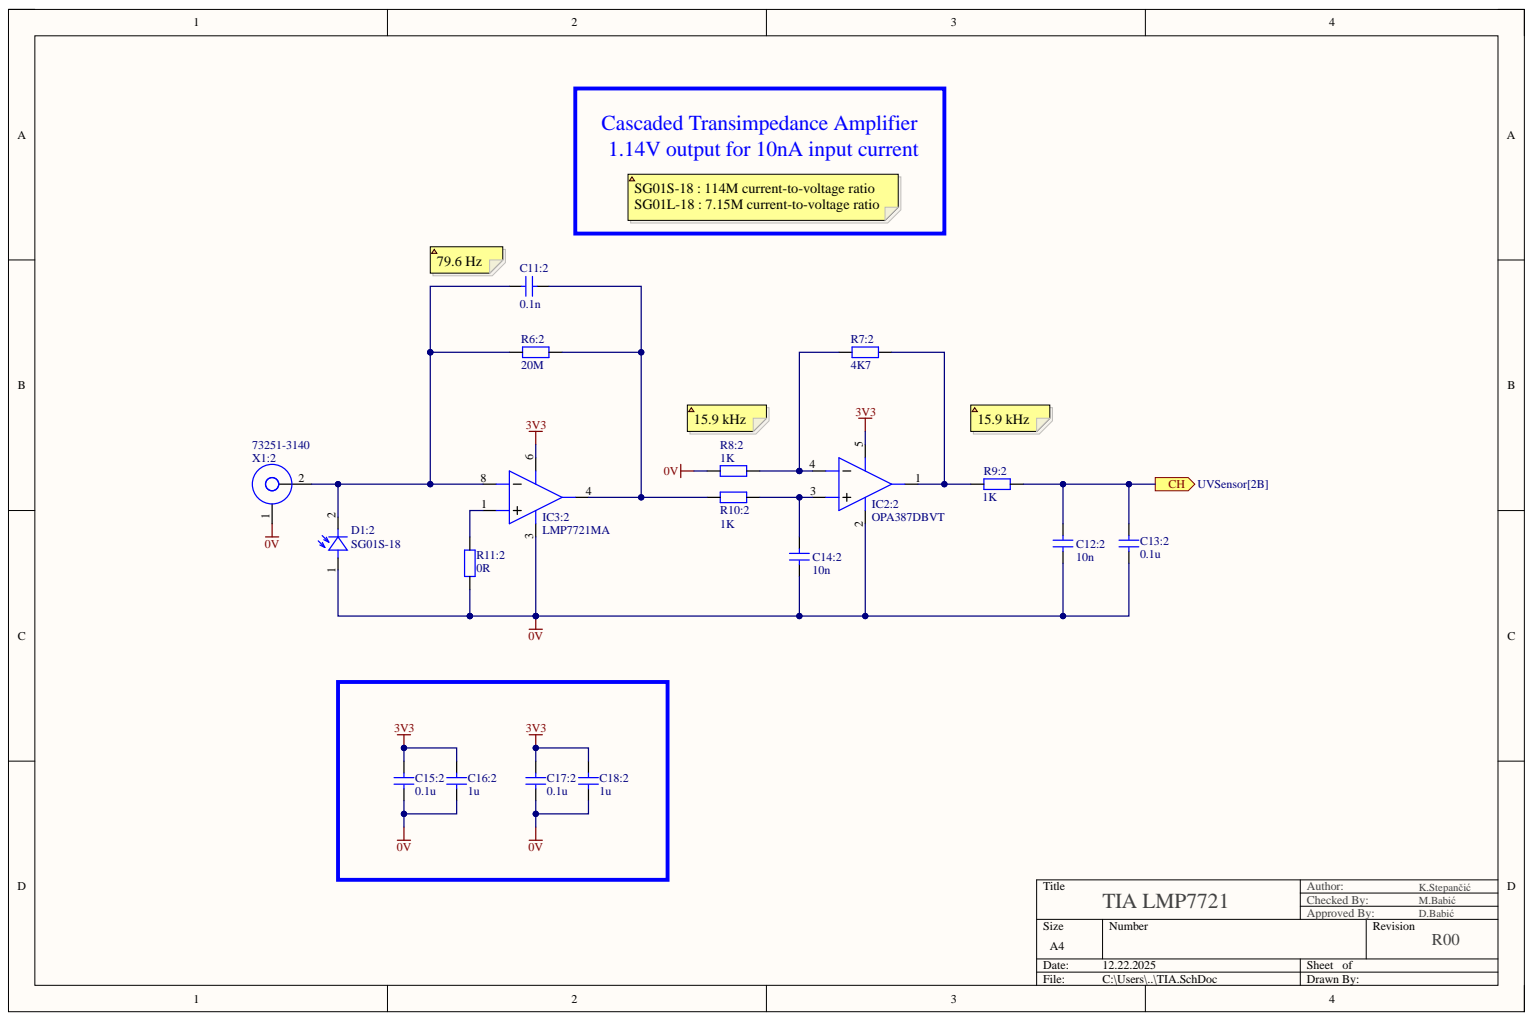
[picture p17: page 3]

Cascaded Transimpedance Amplifier
1.14V output for 10nA input current

SG01S-18 : 114M current-to-voltage ratio
SG01L-18 : 7.15M current-to-voltage ratio

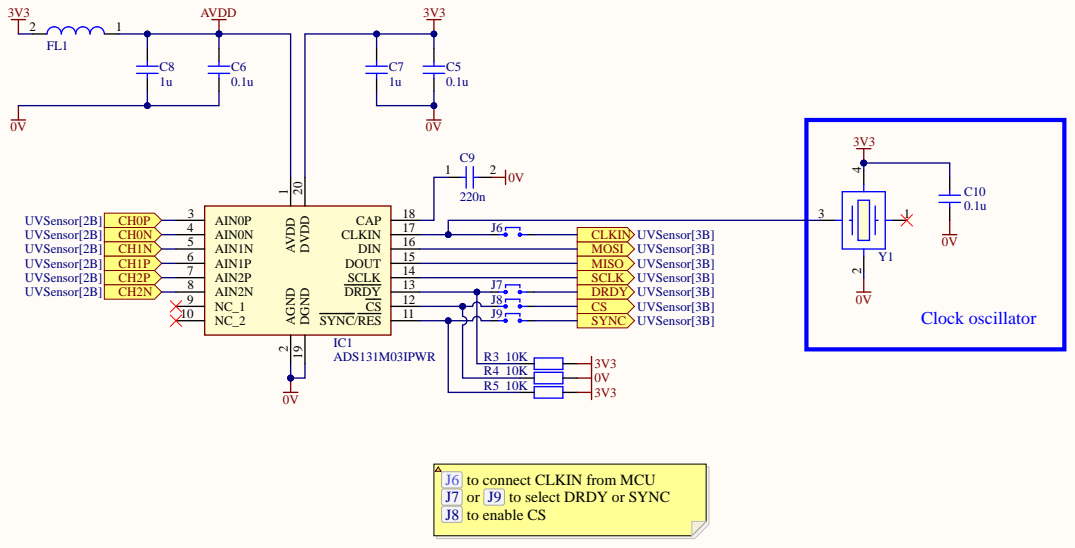
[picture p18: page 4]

J6 to connect CLKIN from MCU
J7 or J9 to select DRDY or SYNC
J8 to enable CS

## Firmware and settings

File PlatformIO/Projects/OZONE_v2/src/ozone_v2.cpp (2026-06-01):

#include "Arduino.h"
#include "ADS131M04.h"
#include <ESP32Servo.h>
#include <TimeLib.h>
//#include <Adafruit_NeoPixel.h>
//#include "Adafruit_TestBed.h"
//#include <Adafruit_ST7789.h> 
//#include <Fonts/FreeSans12pt7b.h>

#define EN 11
#define S0 5
#define ADC_DRDY 6
#define ADC_CS 9

#define ADC_SCK 36
#define ADC_MISO 37
#define ADC_MOSI 35

// 2000 sublists, rotate filters every 10 sublists, calibrate every 200
#define MAX_SUBLISTS 2000 //2000
//#define MAX_CAL 200     //kalibrira se samo jednom na početku mjerenja
#define BLOCKS_PER_PHASE 10   //koliko mjerenja prije okretanja filtera
#define SAMPLES_PER_BLOCK 20   //koliko sample-ova za jedno mjerenje
#define SAMPLES_FOR_CAL 100
#define SERVO_SETTLE_TIME 1000
#define ADC_DISCARD_SAMPLES 5

uint8_t cal_cycles = 0;
int utc_offset = +2;
time_t startTime, endTime;

// #define BUFFER_TIME 60 
// BUFFER_TIME/2(Hz) su sekunde

// INTERRUPT
volatile uint16_t drdy_div = 0;
volatile bool drdy_fall = false; //data ready, seta se interuptom
void IRAM_ATTR adc_ready_interrupt() {
    drdy_div++;
    if (drdy_div >= 100) {
        drdy_div = 0;
        drdy_fall = true;
    }
}

// SVE ADC
ADS131M04 adc1;        //objekt ADC-a
adcOutput adc_podatak; //output tip, pristup kanalima 0-3, status

Servo filter_servo;

int pos1 = 10;
int pos2 = 180;
int pos_cal = 100;

// SKALA
int32_t neg_scale = -8388608;
int32_t pos_scale = 8388607;
float FS = 8388608.0;

float NREF_ADC = -1200.0;
float PREF_ADC = 1200.0;

double Vch0;
double Vch1;
double Vch2;
float Vref = 101.75; //izmjereno stolnim DMM-mom dok je uređaj napajan USB-C kabelom, 101.13 mV kad je napajan baterijom

void printTime();
time_t toUtc(time_t local);
time_t compileTime();
void printElapsed(uint64_t start, uint64_t end);

void setup_ADC_CARD();
void offsetCalibration();
void filter_rotation(int pos);
void measurement(float &mean_ch0, float &sttdev_ch0, float &mean_ch1, float &sttdev_ch1);
void storeMeasurement(float a, float b, float c, float d);

// ---------------- DYNAMIC STORAGE ----------------
float (*measurements)[4] = NULL;
size_t measurement_index = 0;

// ---------------- SETUP ----------------
void setup() {
  pinMode(EN, OUTPUT);
  digitalWrite(EN, HIGH);

  Serial.begin(115200);
  delay(5000);
  setTime(toUtc(compileTime()));
  startTime = millis();

  filter_servo.attach(S0);

  setup_ADC_CARD();
  attachInterrupt(ADC_DRDY, adc_ready_interrupt, FALLING);//interupt na DRDY pin  

  measurements = (float (*)[4])malloc(MAX_SUBLISTS * sizeof(*measurements));
  if (!measurements) {
    Serial.println("Memory allocation failed!");
    while (1);
  }
  delay(3000);
  Serial.println("---- MEASUREMENTS START ----");
  // ------- OFFSET CALIBRATION -------
  filter_rotation(pos_cal);
  offsetCalibration();
}

// ---------------- LOOP ----------------
void loop() {
  
  // ------- PHASE  1 -------
  filter_rotation(pos1);
  for (int i =0; i<BLOCKS_PER_PHASE; i++) {
    float mean_ch0, stddev_ch0, mean_ch1, stddev_ch1;
    measurement(mean_ch0, stddev_ch0, mean_ch1, stddev_ch1);
    storeMeasurement(mean_ch0, stddev_ch0, mean_ch1, stddev_ch1);
  }
  // ------- PHASE  2 -------
  filter_rotation(pos2);
  for (int i =0; i<BLOCKS_PER_PHASE; i++) {
    float mean_ch0, stddev_ch0, mean_ch1, stddev_ch1;
    measurement(mean_ch0, stddev_ch0, mean_ch1, stddev_ch1);
    storeMeasurement(mean_ch0, stddev_ch0, mean_ch1, stddev_ch1);
  }
/*
  // ------- CALIBRATION -------
  if (cal_cycles >= MAX_CAL) {
    kalibracija tokom mjerenja
  }
*/
  // ------- PRINT AND SHUTDOWN -------
  if (measurement_index >= MAX_SUBLISTS) {
    Serial.println("---- DATA START ----");
    for (size_t i = 0; i < MAX_SUBLISTS; i++) {
      Serial.print("[");
      Serial.print(measurements[i][0], 4); Serial.print(",");
      Serial.print(measurements[i][1], 4); Serial.print(",");
      Serial.print(measurements[i][2], 4); Serial.print(",");
      Serial.print(measurements[i][3], 4);
      Serial.println("]");
    }
    Serial.println("---- DATA END ----");
    endTime = millis();
    printElapsed(startTime, endTime);
    Serial.println("Shutting down system...");
    if (measurements != NULL) {
      free(measurements);
      measurements = NULL;
    }
    adc1.sendcmd(CMD_STANDBY);
    delay(5);
    // Disable SPI peripheral
    adc1.end();
    // Tri-state SPI pins
    digitalWrite(ADC_CS, LOW);
    digitalWrite(ADC_SCK, LOW);
    digitalWrite(ADC_MOSI, LOW);

    filter_rotation(pos1);
    // Power down analog board
    digitalWrite(EN, LOW);
    Serial.println("System powered down.");
    while (1) {
      Serial.println("Go to sleep!");
      delay(1000);
    }
  }
}

// ADC INIT
// 2kHz 0b0000001100010010 , 4kHz 0b0000001100001110 , 8kHz 0b0000001100001010
void setup_ADC_CARD() {

  uint32_t ADC_CLOCK_REG = 0b0000011100010010; //High res, Oversampling ratio 4:2 512 oko 2khz, enable samo 0 i 1 ch 001 je 256
  uint32_t ADC_CFG_REG = 0b0000011000000000; //Delay before measurment begins, za kasnije mozda enable
  adc1.begin(ADC_SCK, ADC_MISO, ADC_MOSI, ADC_CS);
  adc1.sendcmd(CMD_RESET);
  delay(10);
  adc1.sendcmd(CMD_STANDBY);
  delay(10);
  adc1.writeRegister(REG_CLOCK, ADC_CLOCK_REG);
  adc1.writeRegister(REG_CFG, ADC_CFG_REG); //
  adc1.writeRegister(THRSHLD_LSB, 0b0000000000000000);

  adc1.setChannelPGA(0, 0); // GAIN 1
  adc1.setChannelPGA(1, 0);
  adc1.setChannelPGA(2, 0);

  adc1.setInputChannelSelection(0, INPUT_CHANNEL_MUX_AIN0P_AIN0N);
  adc1.setInputChannelSelection(1, INPUT_CHANNEL_MUX_AIN0P_AIN0N);
  adc1.setInputChannelSelection(2, INPUT_CHANNEL_MUX_AIN0P_AIN0N);

  delay(10);
  adc1.sendcmd(CMD_WAKEUP);
  delay(10);
}  

// ---------------- FILTER ROTATION ----------------
void filter_rotation(int pos) {

  adc1.sendcmd(CMD_STANDBY);
  delay(10);

  Serial.print("Filter in position ");
  Serial.println(pos);

  filter_servo.write(pos);
  delay(SERVO_SETTLE_TIME);

  adc1.sendcmd(CMD_WAKEUP);
  delay(10);
}

// --------------- OFFSET CALIBRATION ---------------
void offsetCalibration() {
  int32_t m0 = 0;
  int32_t m1 = 0;
  int collected = 0;

  while (collected < SAMPLES_FOR_CAL) {
    if (drdy_fall) {
      drdy_fall = false;
      
      adcOutput temp = adc1.readADC();

      int32_t delta0 = temp.ch0 - m0;
      m0 += delta0 / (collected + 1);

      int32_t delta1 = temp.ch1 - m1;
      m1 += delta1 / (collected + 1);
      collected++;       
    }
  }
  adc1.setChannelOffsetCalibration(0, m0);
  adc1.setChannelOffsetCalibration(1, m1);

  float offset_v0 = m0 / FS * PREF_ADC;
  float offset_v1 = m1 / FS * PREF_ADC;

  Serial.print("Reference voltage: ");
  Serial.print(Vref);
  Serial.println(" mV");
  Serial.print("Offset Calibration: ");
  Serial.print(offset_v0);
  Serial.print(" mV   ");
  Serial.print(offset_v1);
  Serial.println(" mV");
}

// ---------------- READ AND COMPUTE ----------------
void measurement(float &mean_v0, float &stddev_v0, float &mean_v1, float &stddev_v1) {
  double m0 = 0;
  double m1 = 0;
  double s0 = 0;
  double s1 = 0;
  int collected = 0;

  while (collected < SAMPLES_PER_BLOCK) {

    if (drdy_fall) {
      drdy_fall = false;

      adcOutput temp = adc1.readADC();
      Vch0 = temp.ch0 / FS * PREF_ADC;
      Vch1 = temp.ch1 / FS * PREF_ADC;

      double delta0 = Vch0 - m0;
      m0 += delta0 / (collected + 1);
      s0 += delta0 * (Vch0 - m0);

      double delta1 = Vch1 - m1;
      m1 += delta1 / (collected + 1);
      s1 += delta1 * (Vch1 - m1);

      collected++;
    }
  }
  mean_v0 = m0;
  mean_v1 = m1;
  float variance0 = s0 / (SAMPLES_PER_BLOCK - 1);
  float variance1 = s1 / (SAMPLES_PER_BLOCK - 1);
  if (variance0 < 0) variance0 = 0;
  stddev_v0 = sqrt(variance0);
  if (variance1 < 0) variance1 = 0;
  stddev_v1 = sqrt(variance1);

  Serial.print("Prvi kanal: " );
  Serial.print(mean_v0);
  Serial.print(" mV   ");
  Serial.print(stddev_v0);

  Serial.print("   Drugi kanal: " );
  Serial.print(mean_v1);
  Serial.print(" mV   ");
  Serial.println(stddev_v1);
}

// ---------------- STORE ----------------
void storeMeasurement(float a, float b, float c, float d) {
  if (measurement_index >= MAX_SUBLISTS)
    return;

  measurements[measurement_index][0] = a;
  measurements[measurement_index][1] = b;
  measurements[measurement_index][2] = c;
  measurements[measurement_index][3] = d;

  measurement_index++;
  cal_cycles++;
}

void storeOffset(float a, float b, float c, float d) {
  if (measurement_index >= MAX_SUBLISTS)
    return;

  measurements[measurement_index][0] = a;
  measurements[measurement_index][1] = b;
  measurements[measurement_index][2] = c;
  measurements[measurement_index][3] = d;
}

time_t toUtc(time_t local) {
  return local - utc_offset * 3600L;
}

// Code from JChristensen/Timezone Clock example
time_t compileTime() {
  const uint8_t COMPILE_TIME_DELAY = 8;
  const char *compDate = __DATE__, *compTime = __TIME__, *months = "JanFebMarAprMayJunJulAugSepOctNovDec";
  char chMon[4], *m;
  tmElements_t tm;

  strncpy(chMon, compDate, 3);
  chMon[3] = '\0';
  m = strstr(months, chMon);
  tm.Month = ((m - months) / 3 + 1);

  tm.Day = atoi(compDate + 4);
  tm.Year = atoi(compDate + 7) - 1970;
  tm.Hour = atoi(compTime);
  tm.Minute = atoi(compTime + 3);
  tm.Second = atoi(compTime + 6);
  time_t t = makeTime(tm);
  return t + COMPILE_TIME_DELAY;
}
void printTime(time_t t) {
  char buffer[25];
  sprintf(buffer, "%04d-%02d-%02d %02d:%02d:%02d",
          year(t), month(t), day(t),
          hour(t), minute(t), second(t));
  Serial.println(buffer);
}

void printElapsed(uint64_t start, uint64_t end) {

  uint64_t elapsed = end - start;

  uint32_t seconds = elapsed / 1000;
  uint32_t minutes = seconds / 60;
  uint32_t hours = minutes / 60;

  seconds %= 60;
  minutes %= 60;

  Serial.print("Measurement duration: ");
  Serial.print(hours);
  Serial.print("h ");
  Serial.print(minutes);
  Serial.print("m ");
  Serial.print(seconds);
  Serial.println("s");
}

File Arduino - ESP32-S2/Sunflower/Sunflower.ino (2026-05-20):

#include <Arduino.h>
#include <ESP32Servo.h> // include Servo library 

Servo horizontal; // horizontal servo
int servoh = 90; // stand horizontal servo

Servo vertical; // vertical servo 
int servov = 90; // stand vertical servo

// LDR pin connections
int ldrld = A0; //LDR down left
int ldrrt = A1; //LDR top rigt
int ldrrd = A2; //ldr down rigt
int ldrlt = A3; //LDR top left

void setup()  {
  Serial.begin(115200);
  horizontal.attach(12); 
  vertical.attach(13);
}

void loop() {
  int lt = analogRead(ldrlt); // top left
  int rt = analogRead(ldrrt); // top right
  int ld = analogRead(ldrld); // down left
  int rd = analogRead(ldrrd); // down rigt

int dtime = 40; // analogRead(4)/20; 40
int tol = 80;   // analogRead(5)/4;  80

int avt = (lt + rt) / 2; // average value top
int avd = (ld + rd) / 2; // average value down
int avl = (lt + ld) / 2; // average value left
int avr = (rt + rd) / 2; // average value right

int dvert = avt - avd; // check the diffirence of up and down
int dhoriz = avl - avr;// check the diffirence og left and rigt

// check if the diffirence is in the tolerance else change vertical angle
if (abs(dvert) > tol)  {
  if (avd > avt)  {
    servov = ++servov;
    if (servov > 130) { servov = 130; }
  }
  else if (avd < avt) {
    servov= --servov;
    if (servov < 50) { servov = 50; }
  }
  else if (avl == avr)  {}  // do nothing
  vertical.write(servov);
}

// check if the diffirence is in the tolerance else change horizontal angle
if (abs(dhoriz) > tol)  {
  if (avl > avr)  {
    servoh = --servoh;
    if (servoh < 10) { servoh = 10; }
  }
  else if (avl < avr) {
    servoh = ++servoh;
    if (servoh > 170) { servoh = 170; }
  }
  else if (avl == avr)  {}  // do nothing
  horizontal.write(servoh);
}
delay(dtime);
}
